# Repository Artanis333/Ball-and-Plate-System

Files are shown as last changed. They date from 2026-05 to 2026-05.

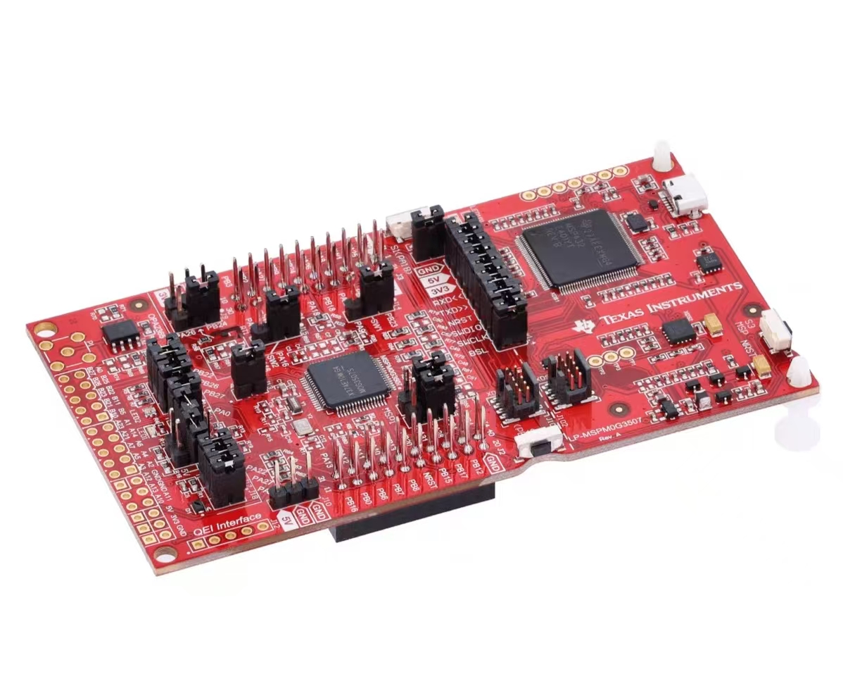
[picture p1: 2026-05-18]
images/mspm0g3507.jpg

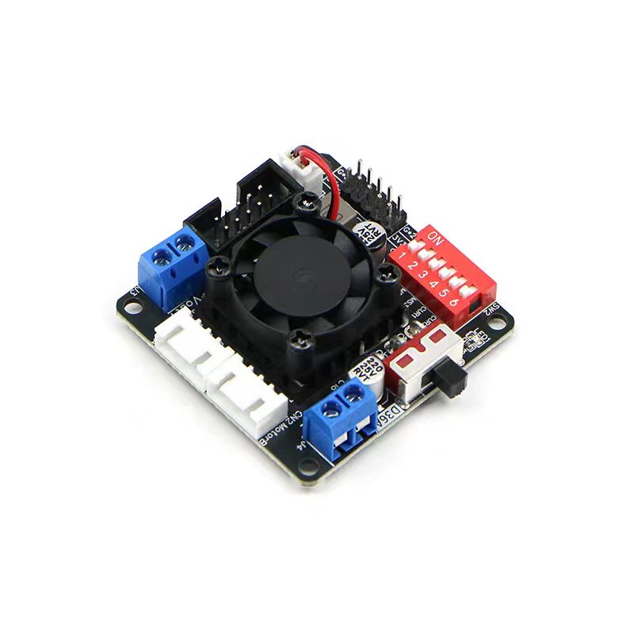
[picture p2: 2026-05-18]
images/d36a.jpg

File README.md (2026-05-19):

# Ball-and-Plate System

基于视觉反馈的板球系统——低成本嵌入式实验平台。

**演示地址：** <https://artanis333.github.io/Ball-and-Plate-System/>

---

## 系统概述

板球系统是一类典型的非线性、强耦合、欠驱动控制对象。本项目搭建了一套基于嵌入式视觉的低成本实验平台，完成了从视觉检测、控制计算到电机执行的完整闭环验证。

### 硬件架构

| 模块 | 型号 | 功能 |
|---|---|---|
| 视觉 | MaixCam | 端侧图像处理，LAB 色彩空间白球检测 |
| 主控 | MSPM0G3507 (TI) | 三环串级 PID 控制，STEP/DIR 脉冲输出 |
| 姿态 | JY931 | 平台倾角实时测量，角度内环反馈 |
| 驱动 | D36A (ATD5984) | 双路 32 细分步进电机驱动 |
| 执行 | 42 步进电机 ×2 | 经摇臂-连杆-万向节传动平台倾斜 |

### 控制策略

三环串级 PID（外环位置 → 中环速度 → 内环角度），采样周期 20 ms (50 Hz)，角度内环以 JY931 实测倾角为反馈。

---

## 仓库结构

```
├── index.html              # 毕业设计答辩演示文稿 (Reveal.js)
├── demo_video.mp4          # 实物闭环运行演示视频
├── images/                 # 演示文稿图片
├── mspm0-modules/          # MSPM0G3507 主控固件 (Code Composer Studio 工程)
│   ├── main.c / main.h     #   主程序：定时中断、串口通信、控制逻辑
│   ├── pid.c / pid.h       #   三环串级 PID 实现
│   ├── mspm0-modules.syscfg #  TI SysConfig 外设配置
│   └── Drivers/            #   传感器驱动
├── vision/                 # MaixCam 视觉端代码 (MicroPython)
│   ├── cam.py              #   白球检测与坐标串口回传
│   └── maixcam_ball_tracker.py  # 备用追踪方案
├── simulink/               # Simulink 仿真模型
│   ├── BallControl3Loop_step.slx        # 定点阶跃响应
│   ├── BallControl3Loop_disturbance.slx # 扰动恢复
│   └── BallControl3Loop_cycle.slx       # 圆轨迹跟踪
├── mechanical/             # 机械结构
│   ├── 材料清单.xlsx        #   完整材料清单
│   ├── MAIXCAM支撑架.stl    #   3D 打印件
│   ├── 中心万向节连接件.stl
│   ├── 侧边万向节连接件.stl
│   └── 光轴底座.stl
├── analysis/               # 数据分析脚本
│   ├── analyze_ball_track.py           # 小球轨迹分析
│   └── draw_mechanical_structure.py    # 机械结构示意图绘制
└── data/
    └── ball_track_1777283591903.csv    # 实物实验轨迹样本数据
```

---

## 复现指南

### 硬件搭建

1. 按 `mechanical/材料清单.xlsx` 采购全部元器件
2. 3D 打印 `mechanical/` 目录下的 STL 文件
3. 组装铝型材框架，安装步进电机、摇臂连杆、万向节和平台面板
4. 将 MaixCam 摄像头安装于平台正上方约 340 mm 处
5. 按引脚定义连接各模块

### 软件部署

**主控端 (MSPM0G3507):**
1. 使用 Code Composer Studio (Theia) 导入 `mspm0-modules/` 目录
2. 编译并烧录到 MSPM0G3507

**视觉端 (MaixCam):**
1. 将 `vision/cam.py` 上传至 MaixCam
2. 确认串口通信参数：波特率 115200，6 字节自定义协议

**仿真环境:**
1. 使用 MATLAB/Simulink 打开 `simulink/` 目录下的 `.slx` 文件
2. 仿真参数已预设，可直接运行

---

## License

MIT License

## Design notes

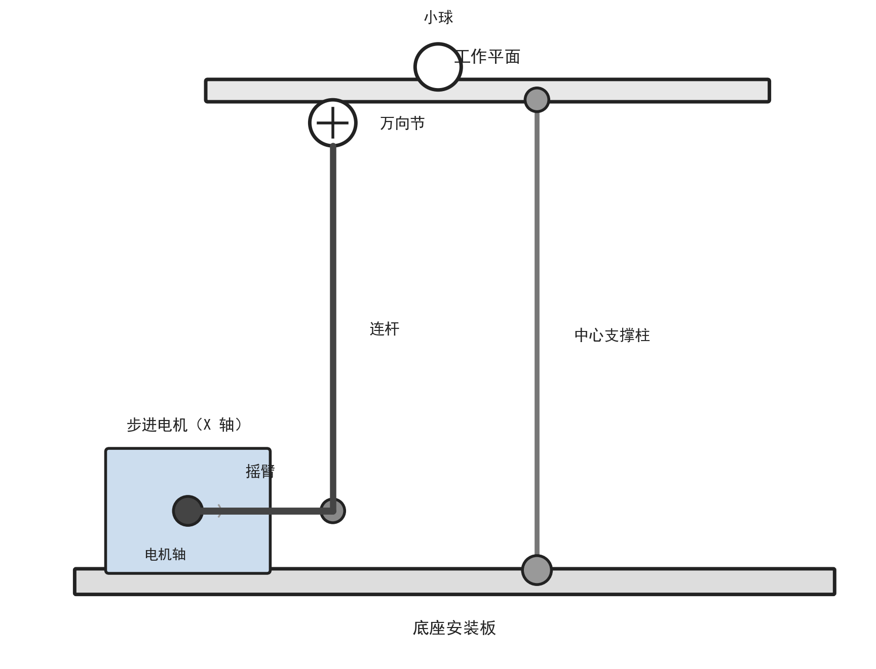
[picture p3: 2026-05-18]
images/mechanical_structure.png

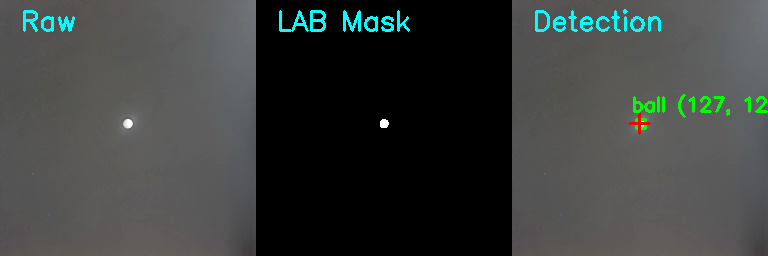
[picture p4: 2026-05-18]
images/vision_pipeline.png

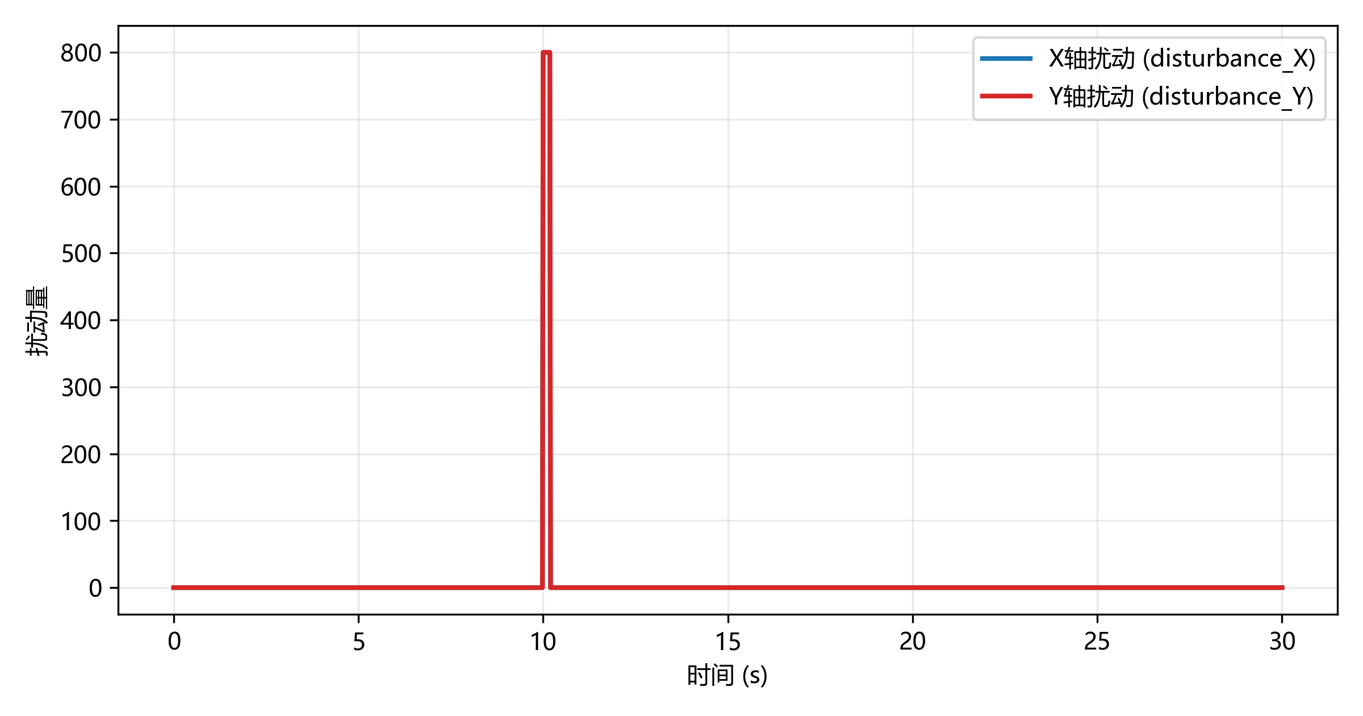
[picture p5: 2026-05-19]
images/sim_disturb_input.png

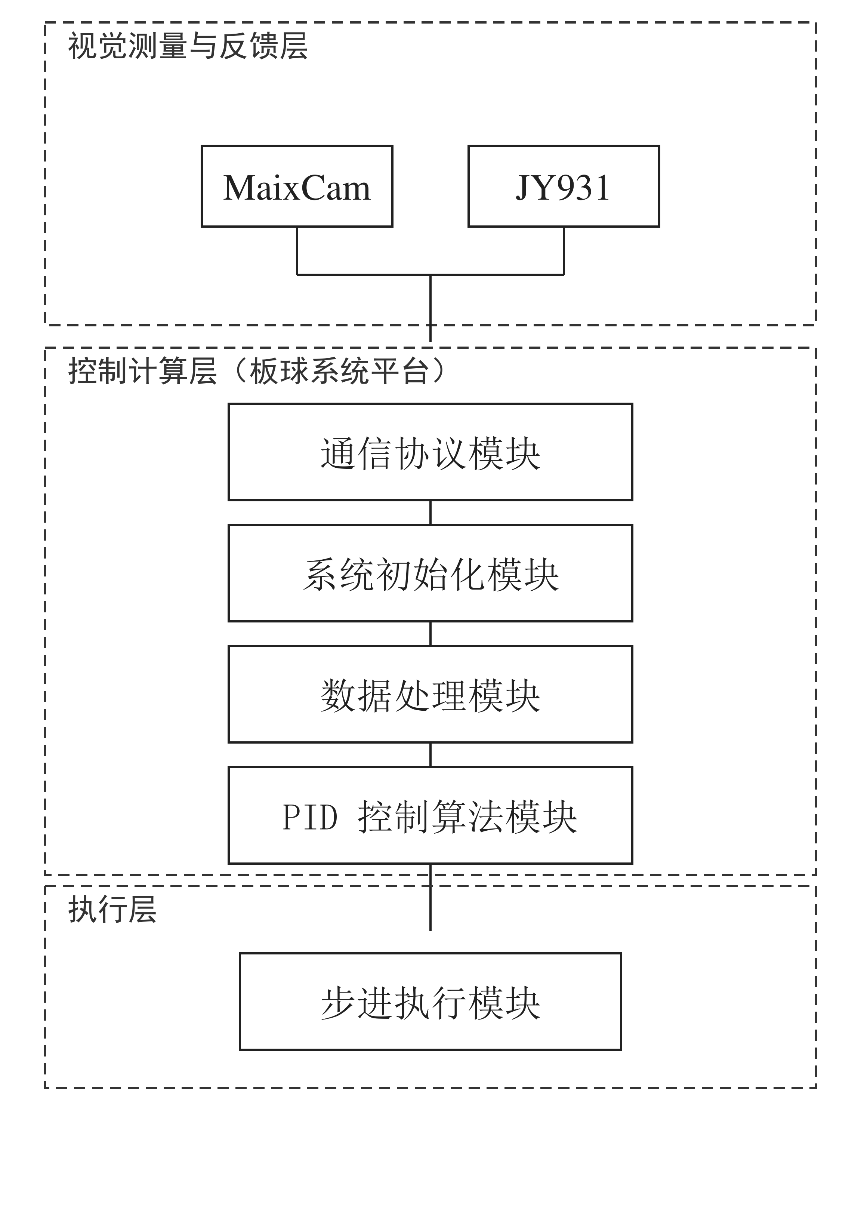
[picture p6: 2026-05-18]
images/software_framework.png

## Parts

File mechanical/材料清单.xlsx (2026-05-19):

品类 | 名称 | 1 | 来源 | 备注
小球 | G5氧化锆陶瓷球12mm | 5 | https://e.tb.cn/h.RcX7iKPs1tR4OuL?tk=Rg1Z5t5m2uB HU287 | 淘宝购买
传动结构件 | 鱼眼杆端轴承 | 2 | https://e.tb.cn/h.R2FOm0KrP5s0F9u?tk=3B3k5t5HlL
 | 十字万向节 | 3 | https://e.tb.cn/h.R2FKEUriGFt38oI?tk=2dxP5t5Epg
 | M6单头外螺纹200mm光轴 | 2 | https://e.tb.cn/h.RcXD5WChPFUGipN?tk=C6lo5tg0hVk
 | 200mm光轴 | 1 | https://e.tb.cn/h.RXKbHCQQz8FXxtL?tk=6m955tgWxaD
 | 6mm铝合金摆臂 | 2 | https://e.tb.cn/h.Rcvndc3PlEAISi8?tk=mhp75tg6EvQ
 | M6、M5螺丝螺母 | 2 | https://e.tb.cn/h.R2v4ZJKhjlet9yl?tk=xh7g5tg8f1a
陀螺仪 | 维特陀螺仪JY931 | 1 | https://e.tb.cn/h.RcWbDGRBMdzHc8h?tk=1XDn5t6TTn8
步进电机 | 42步进电机无编码器 | 2 | https://e.tb.cn/h.RXJ80o1TnwPUfaO?tk=f1ye5t67paA
步进电机驱动 | D36A步进电机驱动 | 1 | https://e.tb.cn/h.RXJr6Cx7N5uWAt4?tk=U1Zb5t6rfEK
摄像头 | MaixCam | 1 | https://e.tb.cn/h.R2wnt7boOsy3Cgi?tk=I5TQ5t6tcpZ
3D打印支架 | MAIXCAM支撑架 | 1 | 本地文件
 | 侧边万向节连接件 | 2
 | 光轴底座 | 1
 | 中心万向节连接件 | 1
工作平台与底座 | 300*300黑色5mm厚磨砂亚克力板 | 1 | https://e.tb.cn/h.RcDUk5VqUT7H4ie?tk=nmnq5t6Cdc5 | 淘宝购买，磨砂面充当工作平面
铝型材框架 | 2020规格-1.5厚-35cm长 | 2 | https://e.tb.cn/h.RcDieTsfwxK6AG0?tk=JlBP5th0Zuk | 淘宝购买
 | 2020规格-1.5厚-20cm长 | 1
 | 2020规格-1.5厚-75cm长 | 1
 | 2020规格-1.5厚-40cm长 | 1
 | 2020角码 | 8 | https://e.tb.cn/h.RXr3BHm2e7xpPbU?tk=qP1u5thVLsE
 | T型螺栓M5*10 | 20 | https://e.tb.cn/h.R2DbNxeEPZXEFUE?tk=U1zF5thf9Be
光轴固定底座 | SHF6光轴固定座 | 1 | https://e.tb.cn/h.R2DfTyByzUdL7QG?tk=cnhb5th8ppN
红色激光笔 | 红色激光笔 | 1 | no matter

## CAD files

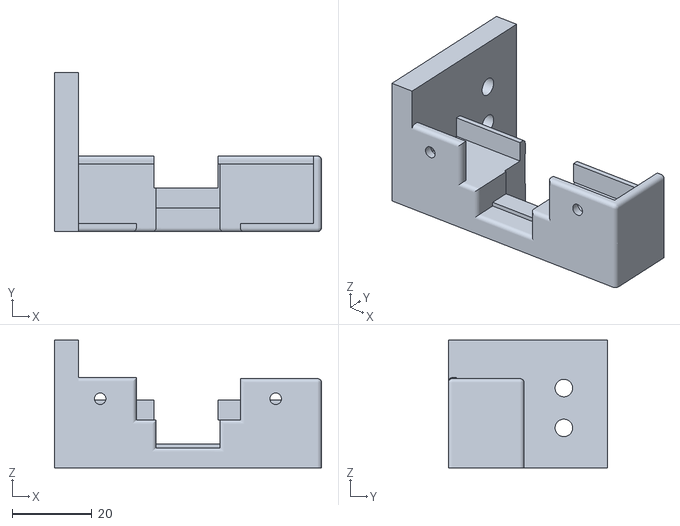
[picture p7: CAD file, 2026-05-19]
mechanical/MAIXCAM支撑架.stl
67.0 x 40.0 x 32.0

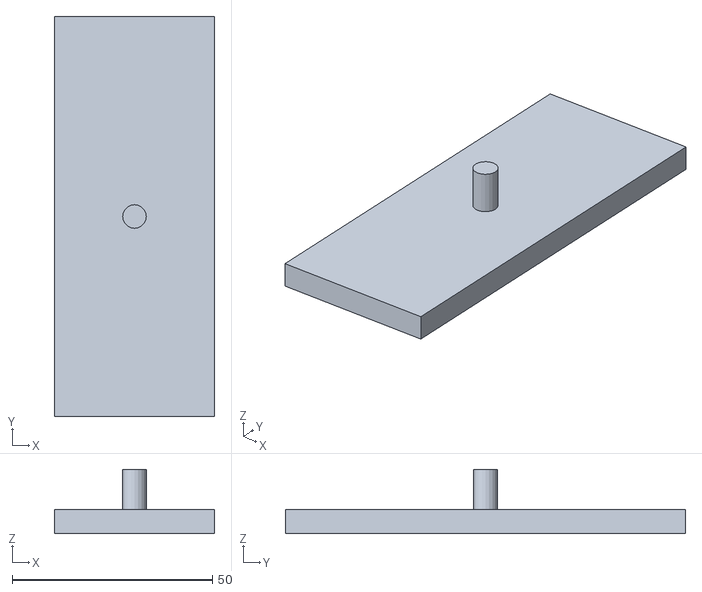
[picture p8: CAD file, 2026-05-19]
mechanical/侧边万向节连接件.stl
40.0 x 100.0 x 16.0

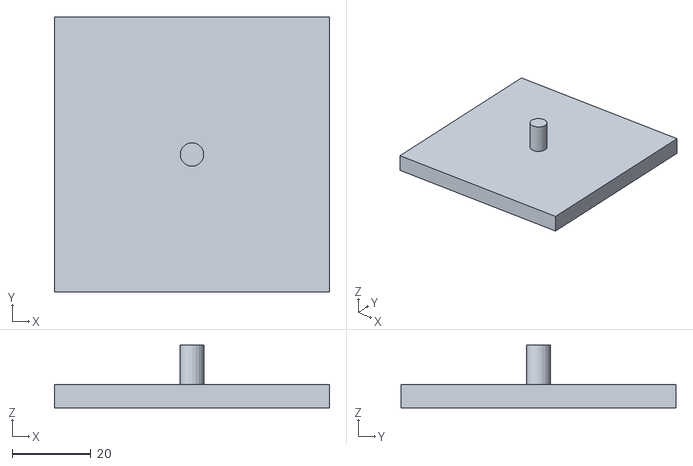
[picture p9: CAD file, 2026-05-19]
mechanical/中心万向节连接件.stl
70.0 x 70.0 x 16.0

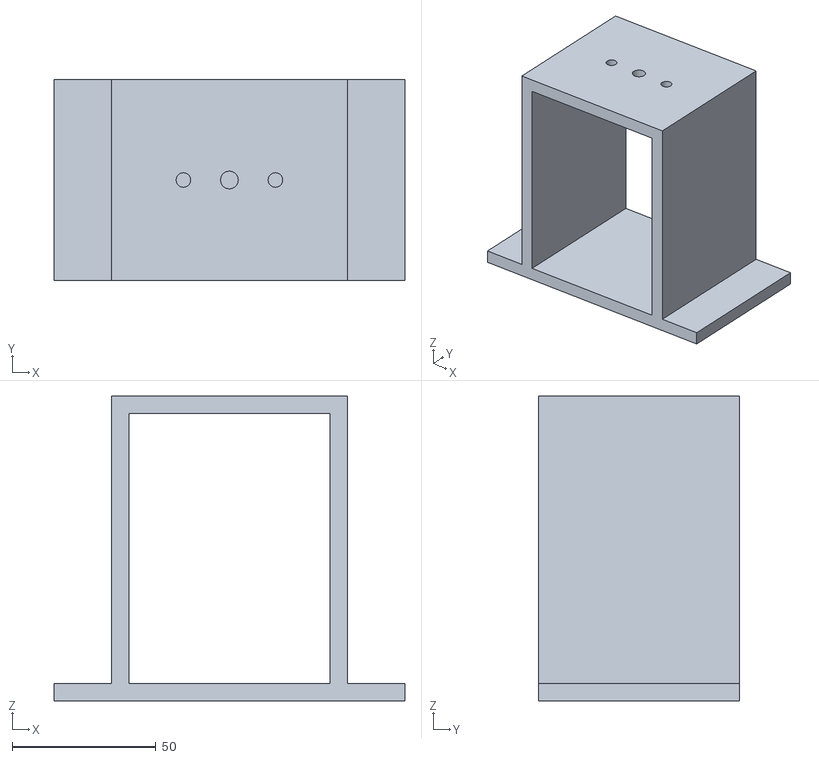
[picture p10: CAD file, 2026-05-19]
mechanical/光轴底座.stl
122.0 x 70.0 x 106.0

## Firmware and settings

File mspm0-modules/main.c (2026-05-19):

/*
 * Copyright (c) 2021, Texas Instruments Incorporated
 * All rights reserved.
 *
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
 * *  Redistributions of source code must retain the above copyright
 *    notice, this list of conditions and the following disclaimer.
 *
 * *  Redistributions in binary form must reproduce the above copyright
 *    notice, this list of conditions and the following disclaimer in the
 *    documentation and/or other materials provided with the distribution.
 *
 * *  Neither the name of Texas Instruments Incorporated nor the names of
 *    its contributors may be used to endorse or promote products derived
 *    from this software without specific prior written permission.
 *
 * THIS SOFTWARE IS PROVIDED BY THE COPYRIGHT HOLDERS AND CONTRIBUTORS "AS IS"
 * AND ANY EXPRESS OR IMPLIED WARRANTIES, INCLUDING, BUT NOT LIMITED TO,
 * THE IMPLIED WARRANTIES OF MERCHANTABILITY AND FITNESS FOR A PARTICULAR
 * PURPOSE ARE DISCLAIMED. IN NO EVENT SHALL THE COPYRIGHT OWNER OR
 * CONTRIBUTORS BE LIABLE FOR ANY DIRECT, INDIRECT, INCIDENTAL, SPECIAL,
 * EXEMPLARY, OR CONSEQUENTIAL DAMAGES (INCLUDING, BUT NOT LIMITED TO,
 * PROCUREMENT OF SUBSTITUTE GOODS OR SERVICES; LOSS OF USE, DATA, OR PROFITS;
 * OR BUSINESS INTERRUPTION) HOWEVER CAUSED AND ON ANY THEORY OF LIABILITY,
 * WHETHER IN CONTRACT, STRICT LIABILITY, OR TORT (INCLUDING NEGLIGENCE OR
 * OTHERWISE) ARISING IN ANY WAY OUT OF THE USE OF THIS SOFTWARE,
 * EVEN IF ADVISED OF THE POSSIBILITY OF SUCH DAMAGE.
 */

#include "ti_msp_dl_config.h"
#include "main.h"
#include <math.h>
int motor_couter[2] = {0},READY_TO_GO = 0,CYCLE_FLAG = 0,CYCLE_TIME = 0,target_x =127,target_y =127;
float motor_location[2] = {0,0};
float SET0_P = 2.35,SET0_R = -1.20,tag_p = 2.35,tag_r =-1.20;
PID_LocTypeDef pid1,pid2,pid3,pid4,pid5,pid6; // 添加中环PID
float ball_vx = 0, ball_vy = 0;
// 圆轨迹参数
#define CIRCLE_CX 127  // 圆心X (图像中心)
#define CIRCLE_CY 127  // 圆心Y
#define CIRCLE_R  75   // 半径
#define LEAD_ANGLE 20  // 超前角度(度)，顺时针为正
// const float vel_filter_alpha = 0.7f; // 速度低通滤波系数，越大滤波越强  // 移除低通滤波
int last_x = 127, last_y = 127; // 假设初始中心

// 卡尔曼滤波结构体
typedef struct {
    float x;      // 状态估计值 (速度)
    float P;      // 估计误差协方差
    float Q;      // 过程噪声协方差
    float R;      // 测量噪声协方差
} KalmanFilter;

KalmanFilter kf_vx, kf_vy;

// 初始化卡尔曼滤波器
void Kalman_Init(KalmanFilter *kf, float initial_x, float P, float Q, float R) {
    kf->x = initial_x;
    kf->P = P;
    kf->Q = Q;
    kf->R = R;
}

// 卡尔曼滤波更新
float Kalman_Update(KalmanFilter *kf, float measurement) {
    // 预测
    float x_pred = kf->x;  // 假设速度恒定
    float P_pred = kf->P + kf->Q;

    // 更新
    float K = P_pred / (P_pred + kf->R);  // 卡尔曼增益
    kf->x = x_pred + K * (measurement - x_pred);
    kf->P = (1 - K) * P_pred;

    return kf->x;
}
int main(void)
{
    
    SYSCFG_DL_init();
    SysTick_Init();
    DL_TimerA_startCounter(PWM_1_INST);
    DL_TimerA_startCounter(TIMER_0_INST);
    NVIC_EnableIRQ(PWM_1_INST_INT_IRQN);
    NVIC_EnableIRQ(TIMER_0_INST_INT_IRQN);
    NVIC_EnableIRQ(GPIO_KEY_INT_IRQN);
    PID_INIT(7, 0.03, 0.001,&pid1);// 内环电机角度PID
    PID_INIT(7, 0.03, 0.001,&pid2);
    PID_INIT(1.1, 0.005, 0.3,&pid3); // 外环位置PID
    PID_INIT(1.1, 0.005, 0.3,&pid4);
    pid3.i_max = 400.0f;              // 位置环积分钳位,防止stick-slip过冲
    pid4.i_max = 400.0f;
    PID_INIT(1.2, 0.01, 0.15,&pid5); // 中环速度PID
    PID_INIT(1.2, 0.01, 0.15,&pid6);
    // MPU6050_Init();
    // OLED_Init();
    // Ultrasonic_Init();
    // BNO08X_Init();
    WIT_Init();
    MAIX_Init();

    // 初始化卡尔曼滤波器
    Kalman_Init(&kf_vx, 0.0f, 1.0f, 0.1f, 1.1f);  // 初始速度0, 协方差1, 过程噪声0.1, 测量噪声1
    Kalman_Init(&kf_vy, 0.0f, 1.0f, 0.1f, 1.1f);
    while (1) 
    {

    }
}
void PWM_1_INST_IRQHandler(void)//
{
    
    if(DL_TimerA_getEnabledInterruptStatus(PWM_1_INST,DL_TIMER_INTERRUPT_ZERO_EVENT) == DL_TIMER_INTERRUPT_ZERO_EVENT)
    {
    if(motor_couter[0]<0)
    {
    DL_TimerA_setCaptureCompareValue(PWM_1_INST, 25, GPIO_PWM_1_C0_IDX);
    DL_GPIO_setPins(GPIO_DIR_PORT, GPIO_DIR_PIN_0_PIN);
    motor_couter[0]++;
    motor_location[0]+=6400/360;
    }
    else if(motor_couter[0]>0)
    {
    DL_GPIO_clearPins(GPIO_DIR_PORT, GPIO_DIR_PIN_0_PIN);
    DL_TimerA_setCaptureCompareValue(PWM_1_INST, 25, GPIO_PWM_1_C0_IDX);
    motor_couter[0]--;
    motor_location[0]-=6400/360;
    }
    else
    {

        DL_TimerA_setCaptureCompareValue(PWM_1_INST, 50, GPIO_PWM_1_C0_IDX);
    }
    if(motor_couter[1]<0)
    {
    DL_GPIO_setPins(GPIO_DIR_PORT, GPIO_DIR_PIN_1_PIN);
    DL_TimerA_setCaptureCompareValue(PWM_1_INST, 25, GPIO_PWM_1_C1_IDX);
    motor_couter[1]++;
    motor_location[1]+=6400/360;
    }
    else if(motor_couter[1]>0)
    {
    DL_GPIO_clearPins(GPIO_DIR_PORT, GPIO_DIR_PIN_1_PIN);
    DL_TimerA_setCaptureCompareValue(PWM_1_INST, 25, GPIO_PWM_1_C1_IDX);
    motor_couter[1]--;
    motor_location[1]-=6400/360;
    }
    else
    {

        DL_TimerA_setCaptureCompareValue(PWM_1_INST, 50, GPIO_PWM_1_C1_IDX);
    }
        
    DL_TimerA_clearInterruptStatus(PWM_1_INST,DL_TIMER_INTERRUPT_ZERO_EVENT);
    if(motor_couter[0]==0&&motor_couter[1]==0) 
    {
    READY_TO_GO = 1;
    }
    else {
    READY_TO_GO = 0;
    }
    }

}
void TIMER_0_INST_IRQHandler(void)
{
    #define VEL_TUNE 0  // 0=正常三环,进入位置环整定
    if (maix_data.flag) {
        // 计算小球速度（微分位置信号）并使用卡尔曼滤波
        float raw_vx = (maix_data.x - last_x) ; // 2ms周期
        float raw_vy = (maix_data.y - last_y) ;
        last_x = maix_data.x;
        last_y = maix_data.y;
        // ball_vx = vel_filter_alpha * ball_vx + (1.0f - vel_filter_alpha) * raw_vx;  // 移除低通滤波
        // ball_vy = vel_filter_alpha * ball_vy + (1.0f - vel_filter_alpha) * raw_vy;
        ball_vx = Kalman_Update(&kf_vx, raw_vx);
        ball_vy = Kalman_Update(&kf_vy, raw_vy);

        // 条件积分:小球一旦运动就清零位置积分,防止stick-slip过冲
        #define VEL_MOVE_THRESH 0.5f
        if(fabsf(ball_vx) > VEL_MOVE_THRESH || fabsf(ball_vy) > VEL_MOVE_THRESH) {
            pid3.location_sum = 0.0f;
            pid4.location_sum = 0.0f;
        }

        // 外环：位置误差 -> 目标速度
        // 圆形轨迹控制
        if(CYCLE_FLAG && CYCLE_TIME>0)
        {
            CYCLE_TIME--;
        // 计算圆轨迹目标点：当前位置角度 + 超前角度
        float dx = maix_data.x - CIRCLE_CX;
        float dy = maix_data.y - CIRCLE_CY;
        float current_angle = atan2f(dy, dx);  // 当前角度 (弧度)
        float target_angle = current_angle - (LEAD_ANGLE * 3.14159f / 180.0f);  // 超前角度 (顺时针)
        target_x = CIRCLE_CX + (int)(CIRCLE_R * cosf(target_angle));
        target_y = CIRCLE_CY + (int)(CIRCLE_R * sinf(target_angle));
        }
        else
        {
            if(maix_data.laser_flag)
            {
        // 激光控制：当存在激光时，目标位置改为激光坐标，
        target_x = maix_data.laser_x;
        target_y = maix_data.laser_y;
        }
        }
        #if VEL_TUNE
        float target_vx = 0.0f;  // 速度环整定:目标速度0,推球观察速度归零响应
        float target_vy = 0.0f;
        #else
        float target_vx = 0.013*PID_location(0, maix_data.x - target_x, &pid3); // 折中缩放
        float target_vy = 0.013*PID_location(0, maix_data.y - target_y, &pid4);
        #endif
        // 中环：速度误差 -> 目标角度
        float target_roll = SET0_R-PID_location(target_vx, ball_vx, &pid5);
        float target_pitch = SET0_P+PID_location(target_vy, ball_vy, &pid6);

        // 内环：角度误差 -> 电机控制
        motor_couter[0] += PID_location(target_roll, wit_data.roll, &pid1);
        motor_couter[1] += PID_location(target_pitch, wit_data.pitch, &pid2);
    } else {
        // 无数据时保持
        motor_couter[0] += PID_location(SET0_R, wit_data.roll, &pid1);
        motor_couter[1] += PID_location(SET0_P, wit_data.pitch, &pid2);
    }
}
void GROUP1_IRQHandler(void)
{
    switch (DL_Interrupt_getPendingGroup(DL_INTERRUPT_GROUP_1)) {
        case GPIO_KEY_INT_IIDX:

            if (!DL_GPIO_readPins(GPIO_KEY_PORT, GPIO_KEY_PIN_PIN)) {
                CYCLE_FLAG = 1;
                CYCLE_TIME = 1000;
            }
            break;
    }
}

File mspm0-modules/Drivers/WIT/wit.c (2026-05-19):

#include "wit.h"

uint8_t wit_dmaBuffer[33];
uint8_t maix_dmaBuffer[6];

WIT_Data_t wit_data;
MAIX_Data_t maix_data;

void WIT_Init(void)
{
    DL_DMA_setSrcAddr(DMA, DMA_WIT_CHAN_ID, (uint32_t)(&UART_WIT_INST->RXDATA));
    DL_DMA_setDestAddr(DMA, DMA_WIT_CHAN_ID, (uint32_t) &wit_dmaBuffer[0]);
    DL_DMA_setTransferSize(DMA, DMA_WIT_CHAN_ID, 32);
    DL_DMA_enableChannel(DMA, DMA_WIT_CHAN_ID);

    NVIC_EnableIRQ(UART_WIT_INST_INT_IRQN);
}
void MAIX_Init(void)
{
    DL_DMA_setSrcAddr(DMA, DMA_MAIX_CHAN_ID, (uint32_t)(&UART_MAIX_INST->RXDATA));
    DL_DMA_setDestAddr(DMA, DMA_MAIX_CHAN_ID, (uint32_t) &maix_dmaBuffer[0]);
    DL_DMA_setTransferSize(DMA, DMA_MAIX_CHAN_ID, 2);
    DL_DMA_enableChannel(DMA, DMA_MAIX_CHAN_ID);

    NVIC_EnableIRQ(UART_MAIX_INST_INT_IRQN);
}

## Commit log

2026-05-19 Restructure to 4-chapter format with expanded modeling
    - 4 chapters with Roman numeral divider slides
    - Dynamics modeling merged into one conclusion-focused slide with state space matrices
    - Disturbance simulation added as separate slide
    - Step + disturbance on same page, circle tracking standalone
    - Vision slide simplified (removed flow text, kept images)
    - Experiment metrics improved with control-theory significance
    - Outline redesigned with left-aligned vertical chapter layout
    - Chapter numbering simplified to Chinese numerals only
2026-05-19 Add project source code, models, and documentation
    - firmware/: MSPM0G3507 control firmware (main, PID, sensor drivers)
    - vision/: MaixCam ball detection code (MicroPython)
    - simulink/: Three Simulink models (step, disturbance, circle)
    - mechanical/: 3D-printable STL files and materials BOM
    - analysis/: Python trajectory analysis and diagram scripts
    - data/: Sample experimental trajectory data
    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
    [MAIXCAM支撑架.stl, ball_track_1777283591903.csv, 中心万向节连接件.stl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]
2026-05-19 Remove personal info from README, restore CCS project, drop draft BOM
    - README: Remove personal name, student ID, advisor, performance metrics
    - Replace firmware/ with original mspm0-modules/ CCS project intact
    - Remove abandoned hardware BOM draft
    [硬件BOM清单_待填写.xlsx]
2026-05-20 Update MAIXCAM support bracket STL
